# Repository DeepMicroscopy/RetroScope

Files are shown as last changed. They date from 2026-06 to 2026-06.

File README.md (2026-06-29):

<picture>
  <source media="(prefers-color-scheme: dark)" srcset="retroscope/qml/icons/app_logo_dark.png">
  <source media="(prefers-color-scheme: light)" srcset="retroscope/qml/icons/app_logo_light.png">
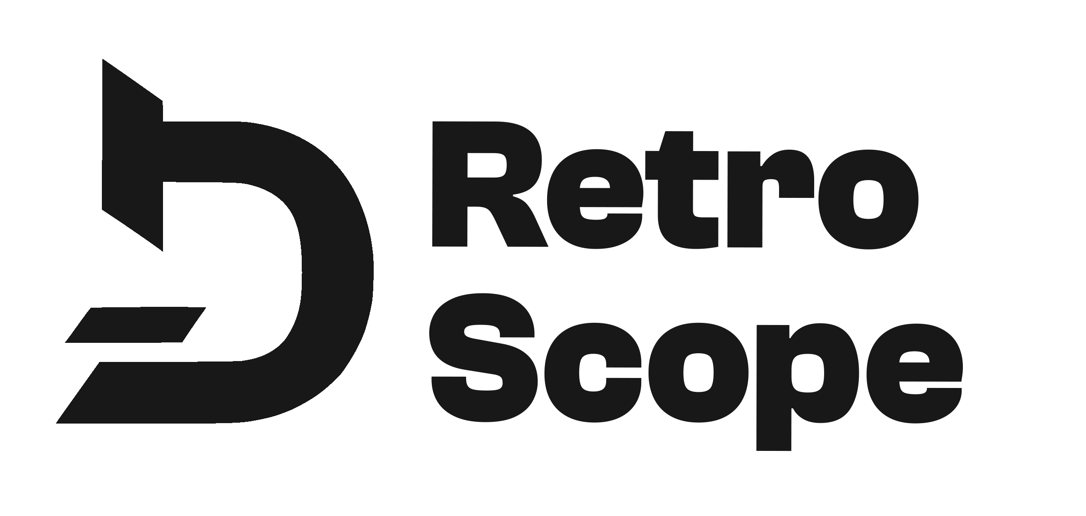
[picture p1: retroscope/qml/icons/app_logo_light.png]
RetroScope
  
</picture>

---

**An Open Framework for Motorizing and Digitizing Vintage Microscopes**

RetroScope is an open-source framework for older analog microscopes. It combines software, digital imaging, motorized stage and focus control, calibration workflows, and adaptable mechanical parts so that existing microscopes can be upgraded instead of replaced.

<p align="center">
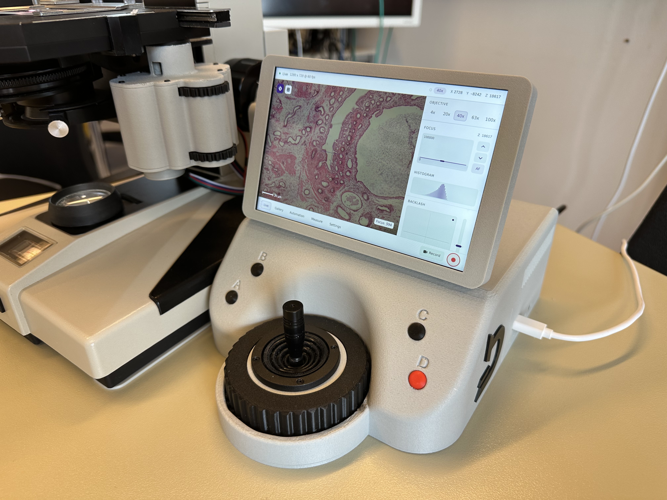
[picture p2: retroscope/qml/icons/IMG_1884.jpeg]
RetroScope
  
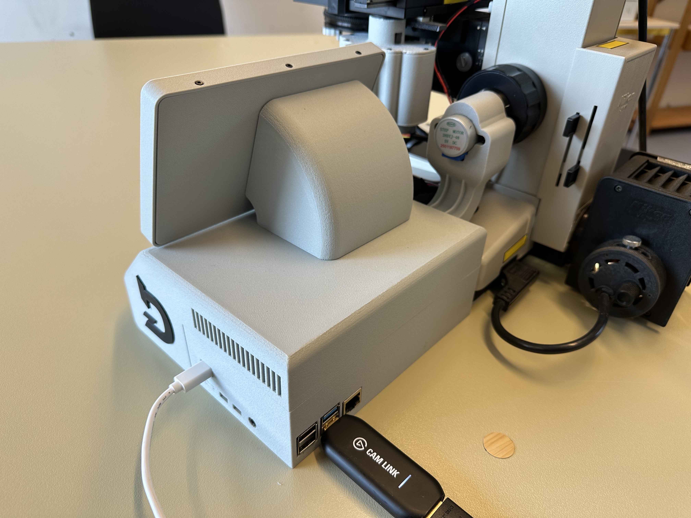
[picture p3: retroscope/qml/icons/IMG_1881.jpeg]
RetroScope
  
</p>

The project was developed as part of the master's thesis **"Retrofitting a Vintage Microscope: Development of an Embedded System for Motorized Control and Digital Imaging"** in Applied Computer Science at Flensburg University of Applied Sciences.

## Overview

RetroScope is not just a single application. It is intended as a complete retrofit framework:

- **Control software**: Python/PySide6 backend with a QML touchscreen interface.
- **Embedded system**: Raspberry Pi-based embedded system with mock/development support for desktop.
- **Motor control**: XY stage and Z focus movement through a motor controller ([Sangaboard](https://build.openflexure.org/openflexure-microscope/v7.0.0-beta5/parts/electronics/sangaboard.html)).
- **Digital imaging**: Live camera preview, snapshots, video recording, OME-TIFF support and gallery management.
- **Automation**: Autofocus, focus stacking and tile scanning with stitching support.
- **REST API**: FastAPI with Swagger/OpenAPI documentation for e.g. external tools.
- **Calibration**: Calibration wizards with objective profiles, pixel scale, stage scale, backlash compensation, etc.
- **Electronics**: PCB schematics and Gerber files for manufacturing. Optional, just used to reduce the amount of cabling.
- **Mechanical design**: Parametric Fusion/CAD files and 3D-printable parts for adapting the retrofit to different microscopes.

## Features

- Low-latency live microscope view with overlays such as crosshair, scale bar and grid.
- Objective profile system for different magnifications and numerical apertures.
- Camera-assisted calibration for image scale, stage scale, and backlash compensation
- Manual stage and focus control through touchscreen, joystick, and configurable buttons.
- Contract-based autofocus.
- Automated focus stacks and tile scans.
- Measurement tools for distances, rectangles and angles.
- Gallery for snapshots, videos, focus stacks, scans, and tagging.
- REST API to access captures and trigger actions like autofocus.
- Configurable dark/light UI
- Mock mode for development without microscope hardware.

## Screenshots

<p align="center">
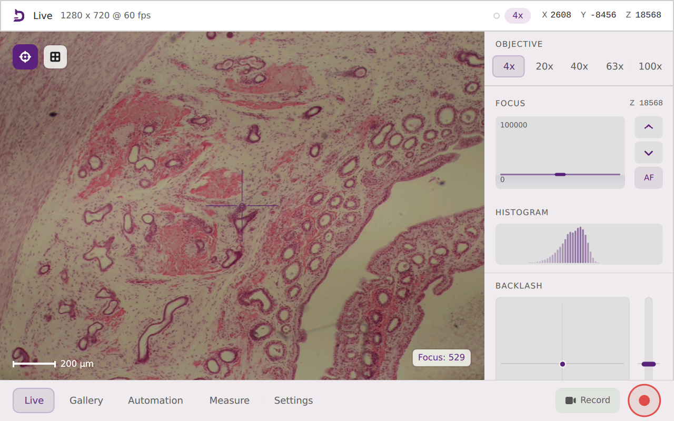
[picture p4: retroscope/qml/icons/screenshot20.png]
RetroScope
  
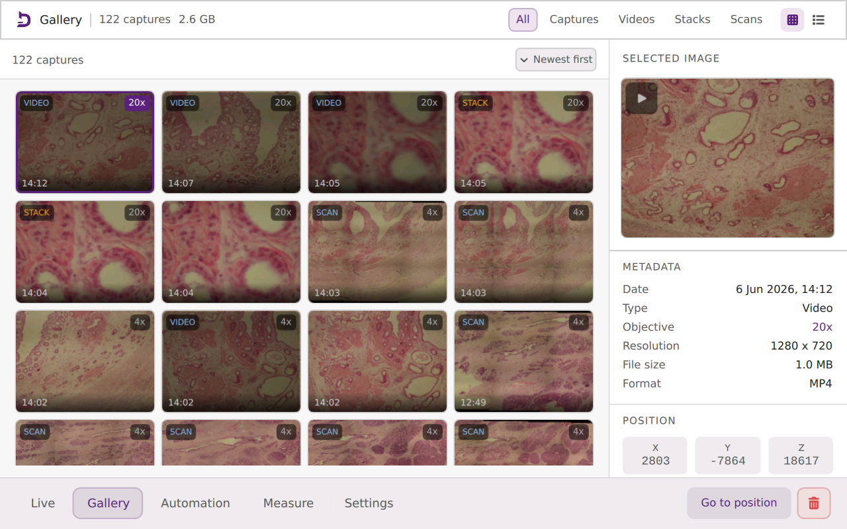
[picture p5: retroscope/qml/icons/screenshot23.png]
RetroScope
  
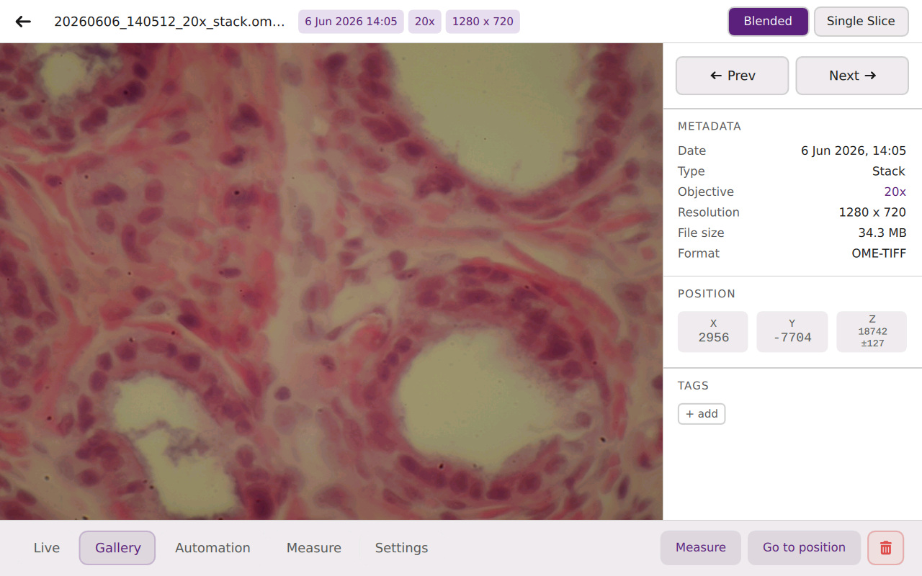
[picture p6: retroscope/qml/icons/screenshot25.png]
RetroScope
  
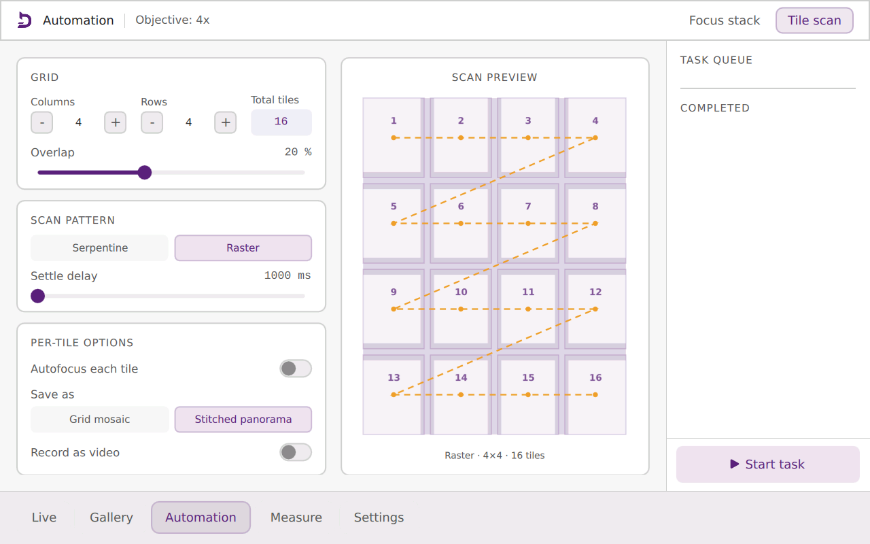
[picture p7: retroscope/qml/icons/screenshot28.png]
RetroScope
  
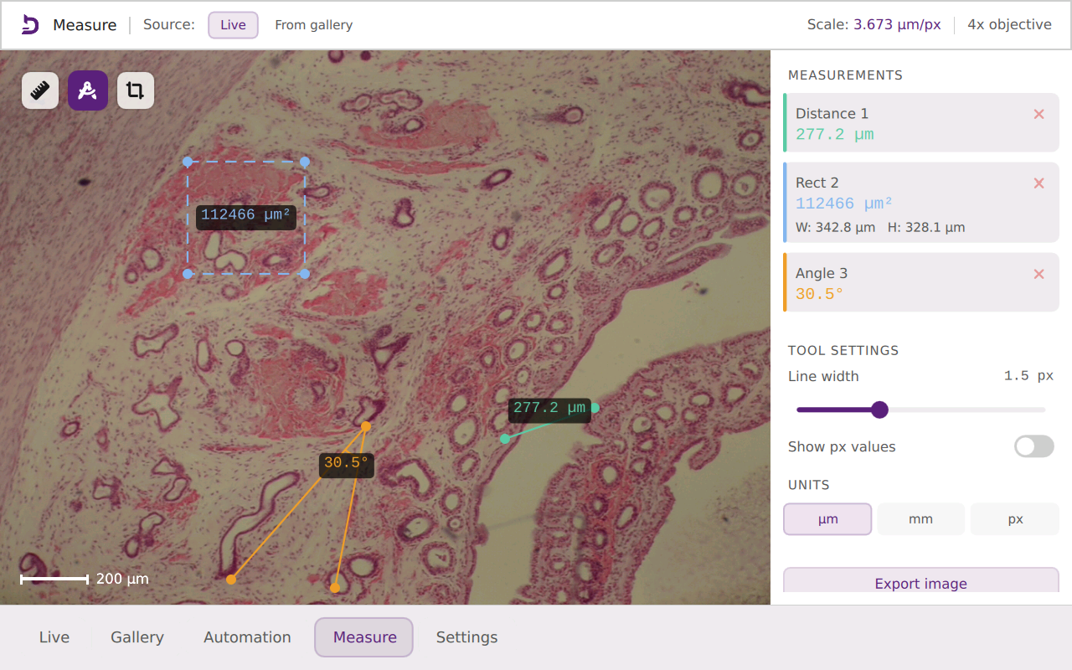
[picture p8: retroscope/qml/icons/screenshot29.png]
RetroScope
  
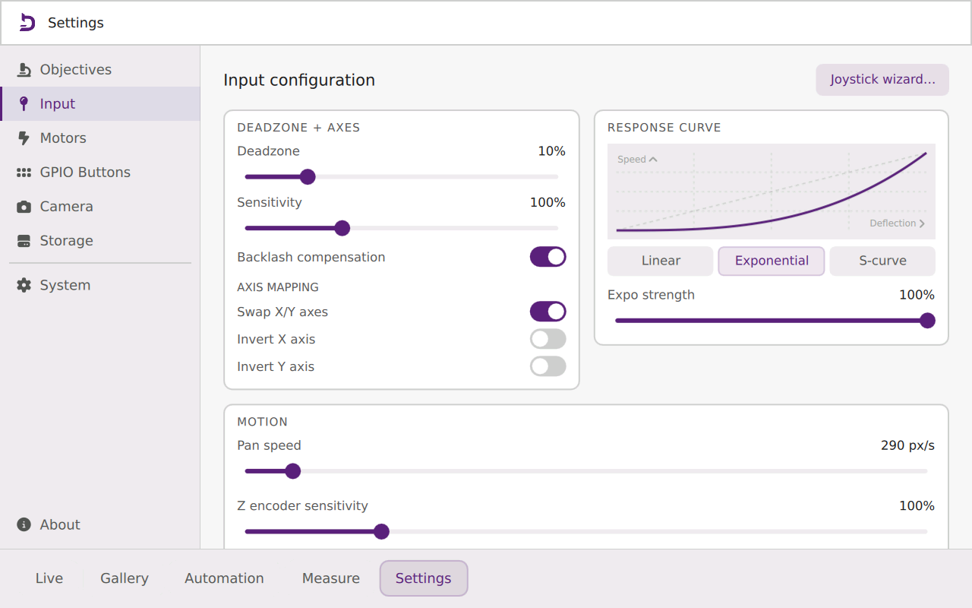
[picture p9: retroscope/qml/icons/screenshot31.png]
RetroScope
  
</p>

## Software Architecture

The software is organized into modular layers:

- `retroscope/drivers`: Low-level hardware drivers for camera input, Sangaboard motor control, joystick ADC, buttons, and endstop.
- `retroscope/services`: Application logic for motion, autofocus, calibration, camera processing, tile scanning, focus stacking, updates, ...
- `retroscope/api`: FastAPI REST interface and OpenAPI/Swagger documentation.
- `retroscope/domain`: Pure domain modules (+ calculations) for scan planning, focus metrics, objective calibration, measurement, ...
- `retroscope/bridge`: Qt/PySide bridge objects that expose APIs to QML.
- `retroscope/qml`: Touchscreen user interface components and views.
- `tests`: Unit tests for calibration, autofocus, motion, scanning, settings, ...

This separation enables the expansion of individual subsystems without rewriting the entire platform.

## Hardware Recommendations

The following parts were used for the prototype:

- Raspberry Pi 4 Model B, 4 GB RAM
- [Sangaboard](https://build.openflexure.org/openflexure-microscope/v7.0.0-beta5/parts/electronics/sangaboard.html)
- 3x 28BYJ-48 Stepper Motors
- DSI Capacitive Touch Display
- Analog Joystick with 10k Potentiometers
- ADS1115 ADC Modul
- Incremental Rotary Encoder
- Bearing (60mm * 78mm * 10mm)
- Endstop
- 4x Buttons
- Various cables
- ABS (& PETG) filament/s for 3D printed parts
- Optional Custom PCB

## Installation

Clone the repository and create a virtual environment:

```bash
git clone https://github.com/marvincarstensen/RetroScope.git
cd retroscope
python[3] -m venv .venv
source .venv/bin/activate
pip install -r requirements.txt
```

For Raspberry Pi deployment, an additional setup script, to e.g. setup the service, has to be run with sudo:
```bash
sudo bash deploy/setup.sh
```

## Running

Start the application:

```bash
python app.py
```
> [!NOTE]
> First launch may take a little longer while Python builds its caches.

Run in mock mode for desktop env:

```bash
python app.py --mock
```

Enable development mode with QML hot reloading:

```bash
python app.py --mock --dev
```

Apply a UI scale factor:

```bash
python app.py --scale 1.5
```

On the Raspberry Pi with Wayland:

```bash
WAYLAND_DISPLAY=wayland-0 XDG_RUNTIME_DIR=/run/user/1000 python app.py --scale=1.5
```

## Testing

Run the test suite:

```bash
.venv/bin/python -m pytest -q
```

Compile-check on the package:

```bash
.venv/bin/python -m compileall -q retroscope
```

Run QML lint checks:

```bash
.venv/bin/pyside6-qmllint -I retroscope/qml $(find retroscope/qml -name '*.qml')
```

## Evaluation

The evaluations run inside the main application so they use the real camera pipeline, motion
services, calibration state, and workflow services. Results are written as CSV files to
`evaluation_output/`, with per-trial rows followed by summary rows. Needs a textured specimen and a safe stage position to run properly. The active objective needs to be selected and calibrated before running measurements.

Available evaluation types:

- `motion_accuracy`: compares commanded X/Y movement with measured image displacement and backlash residuals.
- `stage_scale`: measures repeated stage-scale estimates in micrometres per motor step.
- `calibration_repeat`: repeats stage-scale and backlash checks for the active objective.
- `workflow_reliability`: runs autofocus, focus stacking, and tile scanning through the app services.

Example runs:

```bash
python app.py --eval motion_accuracy --eval-arg axes=xy --eval-arg steps=100,200 --eval-arg reps=10
python app.py --eval stage_scale --eval-arg steps=100 --eval-arg reps=10
python app.py --eval calibration_repeat --eval-arg stage_steps=200 --eval-arg reps=10
python app.py --eval workflow_reliability --eval-arg reps=10 --eval-arg workflows=autofocus,focus_stacking,tile_scanning
```

## REST API

By default, the API is enabled and listens on port `8765`:

- `http://127.0.0.1:8765` / `http://<device-ip>:8765`
- Swagger UI: `http://<device-ip>:8765/docs`
- OpenAPI JSON: `http://<device-ip>:8765/openapi.json`

The current API is intentionally small and intended as an extension point for scripts, notebooks, and external tools.

Endpoint                                  | Description
------------------------------------------|-------------------------------
`GET /api/v1/health`                      | API health check.
`GET /api/v1/captures`                    | List gallery captures.
`GET /api/v1/captures/{id}/download`      | Download the original capture file.
`POST /api/v1/actions/autofocus`          | Start autofocus.
`POST /api/v1/actions/capture`            | Start capture.

## Demo Notebook

The repository contains a basic Jupyter notebook, `retroscope_api_demo.ipynb`, that demonstrates how to use the REST API.

## Shortcuts (Mock only)

The following keyboard shortcuts can be used in mock simulation:

Key       | Function           
----------|-------------------
WASD      | Joystick axes        
Space     | Joystick center (release)         
+/-       | Encoder step +-1       
1/2/3/4   | Button press 0–3      
E         | Simulate endstop triggered/released toggle

## Dependencies

The following plugins, libraries and frameworks are used:

Name                    | Version           
------------------------|-------------------
PySide6                 | 6.11.1
fastapi                 | 0.136.3
httpx2                  | 2.3.0
uvicorn                 | 0.49.0
numpy                   | 2.4.6
pytest                  | 9.0.3
opencv-python-headless  | 4.13.0.92
Pillow                  | 12.2.0
tifffile                | 2026.5.15
sangaboard              | 0.3.3
smbus2 (only on Pi)     | 0.6.1           
gpiod (only on Pi)      | 2.4.2   

## Additional Sources

- Font Awesome by Dave Gandy (https://fontawesome.com/)
- LateX Template, Logo & CI (DeepMicroscopy) by Nils Porsche

## Declaration: Use of Generative AI

The following generative AI tools were used in this thesis: 

- GitHub Copilot in VS Code was used for inline code-completion suggestions during implementation and writing.
- ChatGPT (OpenAI) & Claude (Anthropic) used to support brainstorming, quick research, and the generation of selected parts of the code (e.g. unit tests). AI-assisted scripts and functions are marked in the source code via comments.
- DeepL write (DeepL SE) were used in language editing and grammatical proof-reading.

All AI-generated material was critically reviewed, edited, and verified by the author. No generative AI system was used to produce original scientific results, experimental data, proofs, or final implementations of algorithms. The author assumes full responsibility for the content, correctness, and originality of this thesis.

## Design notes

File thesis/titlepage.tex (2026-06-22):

\begin{tikzpicture}[remember picture,overlay]
  \node[
    anchor=north east,
    xshift=-1cm,
    yshift=-1cm,
    inner sep=0pt   % additional spacing
  ] at (current page.north east) {%
    %
  };
\end{tikzpicture}

\vspace*{-2cm}

\begin{center}
    \textbf{Hochschule Flensburg}\\
    Flensburg University of Applied Sciences\\
    \vspace{2cm}
    \textbf{\LARGE M A S T E R \ \ T H E S I S}
\end{center}

\vspace{2cm}

\begin{tabbing}
    Topic: \hspace{3cm} \= \textbf{Retrofitting a Vintage Microscope:}\\[0.1cm]
    \> Development of an Embedded System for \\[0.1cm]
    \> Motorized Control and Digital Imaging \\[0.5cm]
    by: \> \textbf{Marvin Carstensen}\\[2cm]
    Student ID number: \>\textbf{780241} \\[0.5cm]
    Degree course: \> \textbf{Applied Computer Science (M.Sc.)} \\[0.5cm]
    Supervisor and \\
    primary evaluator: \>\textbf{Prof. Dr.-Ing. Marc Aubreville} \\[0.5cm]
    Secondary evaluator: \> \textbf{Prof. Dr. Simon Olberding} \\[0.5cm]
    Date of issue: \> \textbf{24.03.2026} \\[0.5cm]
    Date of submission: \> \textbf{22.06.2026}
\end{tabbing}

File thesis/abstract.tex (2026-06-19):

Many optical microscopes remain mechanically and optically useful for decades, even when they no longer match the digital and automated workflows expected in modern laboratories or teaching environments. Replacing such instruments can be expensive and wasteful. This thesis investigates whether a vintage microscope can instead be extended with motorized movement, digital imaging, calibration, and automated capturing while preserving the existing microscope body.

The result is RetroScope, an open retrofit platform for motorizing and digitizing vintage microscopes. The prototype attaches motors to the microscope's existing focus and XY-stage controls instead of replacing the whole microscope. A parametric 3D-printable adapter model is used so that important dimensions, such as knob positions and mounting geometry, can be adjusted for various microscope bodies. The system combines low-cost embedded hardware, a custom printed circuit board, a Raspberry Pi, a camera input, and a touchscreen user interface.

The software is designed as a modular application that connects hardware control, live video, calibration, image storage, and automated workflows. Image-based calibration links camera pixels, motor steps, objective profiles, scale information, focus settings, and backlash compensation. This allows the system to support practical workflows such as autofocus, focus stacking, tile scanning, calibrated measurement, and remote access via REST API.

The evaluation shows that the prototype can support these workflows under controlled conditions and that calibration and compensation are essential for making low-cost open-loop mechanics usable. At the same time, the results show clear limitations: the system estimates position from motor commands rather than measuring it directly, and mechanical flex, and backlash still bound the achievable accuracy. RetroScope therefore does not replace a precision research microscope. Instead, it demonstrates a resource-conscious way to give vintage microscopes programmable motion, workflows, and digital capture without discarding the original instrument.

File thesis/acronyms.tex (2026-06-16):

\begin{acronym}[OME-TIFF]
    \acro{ABS}[ABS]{Acrylonitrile butadiene styrene, a printable thermoplastic used for stronger prototype parts.}
    \acro{ABSGF}[ABS-GF]{Glass-fiber-reinforced acrylonitrile butadiene styrene, used for stiffer printed parts.}
    \acro{ADC}[ADC]{Analog-to-digital converter, used to convert analog joystick voltages into digital values.}
    \acro{AF}[AF]{Autofocus.}
    \acro{AI}[AI]{Artificial intelligence.}
    \acro{API}[API]{Application programming interface, a software interface exposed for other programs.}
    \acro{BCM}[BCM]{Broadcom GPIO numbering scheme used by the Raspberry Pi.}
    \acro{BSS138}[BSS138]{A MOSFET commonly used in small logic-level shifter modules.}
    \acro{CAD}[CAD]{Computer-aided design.}
    \acro{CPU}[CPU]{Central processing unit.}
    \acro{CSV}[CSV]{Comma-separated values, a plain-text table format used for evaluation results.}
    \acro{DoF}[DoF]{Depth of field.}
    \acro{DSI}[DSI]{Display Serial Interface, used by the Raspberry Pi touchscreen.}
    \acro{FIFO}[FIFO]{First in, first out, a queue behavior used in serial communication buffers.}
    \acro{GB}[GB]{Gigabyte.}
    \acro{GND}[GND]{Ground reference in the electronics wiring.}
    \acro{GPIO}[GPIO]{General-purpose input/output pins on the Raspberry Pi.}
    \acro{I2C}[I\textsuperscript{2}C]{Inter-Integrated Circuit, a serial bus used by the ADC, current sensors, and touchscreen controller.}
    \acro{JSON}[JSON]{JavaScript Object Notation, a structured text format used for configuration and API data.}
    \acro{JST}[JST]{A family of small electrical connector types used in wiring harnesses.}
    \acro{NA}[NA]{Numerical aperture of a microscope objective.}
    \acro{OME}[OME]{Open Microscopy Environment.}
    \acro{OMETIFF}[OME-TIFF]{Open Microscopy Environment TIFF, a microscopy image format with structured metadata.}
    \acro{OMEXML}[OME-XML]{Open Microscopy Environment XML metadata embedded in or associated with microscopy image files.}
    \acro{OpenCV}[OpenCV]{Open Source Computer Vision Library.}
    \acro{PCB}[PCB]{Printed circuit board.}
    \acro{PETG}[PETG]{Polyethylene terephthalate glycol, a 3D-printing filament material.}
    \acro{PNG}[PNG]{Portable Network Graphics image format.}
    \acro{QML}[QML]{Qt Modeling Language, the declarative language used for the touchscreen user interface.}
    \acro{REST}[REST]{Representational State Transfer, an architectural style used for the HTTP API.}
    \acro{RQ}[RQ]{Research question.}
    \acro{SCL}[SCL]{Serial clock line of an I\textsuperscript{2}C bus.}
    \acro{SDA}[SDA]{Serial data line of an I\textsuperscript{2}C bus.}
    \acro{STEP}[STEP]{Standard for the Exchange of Product Data, a CAD exchange file format.}
    \acro{TIFF}[TIFF]{Tagged Image File Format.}
    \acro{UART}[UART]{Universal asynchronous receiver-transmitter, a serial communication interface.}
    \acro{UI}[UI]{User interface.}
    \acro{USB}[USB]{Universal Serial Bus.}
    \acro{UVC}[UVC]{USB Video Class, a standard for USB camera and capture devices.}
    \acro{V4L2}[V4L2]{Video4Linux2, the Linux video capture interface.}
\end{acronym}

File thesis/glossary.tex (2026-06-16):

\makeglossaries

\newglossaryentry{retrofitting}
{
    name={retrofitting},
    description={the modification of an existing instrument, system or machine so that it gains functionality that was not part of the original design}
}

\newglossaryentry{backlash}
{
    name={backlash},
    description={lost motion that occurs when a drive mechanism changes direction before mechanical contact is re-established}
}

\newglossaryentry{frameanalysis}
{
    name={frame analysis},
    description={the reduced-rate image-processing path used for histogram computation, focus scoring, calibration support, and related live metrics}
}

\newglossaryentry{ometiff}
{
    name={OME-TIFF},
    description={an image format that stores microscopy image planes in TIFF files and encodes microscopy metadata using the OME data model}
}

\newglossaryentry{openloop}
{
    name={open-loop control},
    description={motion control in which motor commands are issued without continuous measurement of the resulting physical position}
}

\newglossaryentry{sangaboard}
{
    name={Sangaboard},
    description={an open-source motor-controller board that drives stepper motors and reports motor step counts to a host over a serial (UART) link}
}

\newglossaryentry{hysteresisband}
{
    name={hysteresis-band model},
    description={a backlash-compensation model that tracks a per-axis slack estimate within a band whose width equals the measured backlash, adding the slack take-up to a move only when the direction reverses}
}

\newglossaryentry{pixelscale}
{
    name={pixel scale},
    description={the physical distance in the specimen plane that corresponds to image pixels for a given objective and camera configuration, expressed in micrometers per pixel}
}

\newglossaryentry{stagescale}
{
    name={stage scale},
    description={the physical stage movement produced by one motor step, calibrated separately for the X and Y axes and expressed in micrometers per step}
}

\newglossaryentry{objectiveprofile}
{
    name={objective profile},
    description={the stored set of per-objective calibration values, including magnification, numerical aperture, pixel scale, backlash, depth-of-field steps, focus-stack step, and autofocus range}
}

\newglossaryentry{depthoffield}
{
    name={depth of field},
    description={the range of object distances along the optical axis that appears acceptably sharp at a given objective, used to choose focus-stack spacing and autofocus range}
}

\newglossaryentry{focusstacking}
{
    name={focus stacking},
    description={the capturing of several images at different focus positions and their combination into a single image with greater apparent depth of field}
}

\newglossaryentry{tilescanning}
{
    name={tile scanning},
    description={the capturing of a grid of overlapping fields of view that are combined into a larger image, either as a stitched panorama or as a deterministic grid mosaic}
}

\newglossaryentry{phasecorrelation}
{
    name={phase correlation},
    description={a frequency-domain image-registration method used to estimate the sub-pixel translational shift between overlapping tiles during stitching}
}

\newglossaryentry{deadzone}
{
    name={dead zone},
    description={a region of small joystick deflection around the center that is mapped to zero motion to prevent drift from noise or imperfect centering}
}

\newglossaryentry{mockmode}
{
    name={mock mode},
    description={a desktop development mode in which hardware-dependent drivers are replaced by stand-ins so that the application can run without the physical microscope}
}

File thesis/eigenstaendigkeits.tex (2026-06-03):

I hereby declare that I have written this thesis independently and without outside help, that I have used no sources or aids other than those indicated, that I have marked all passages taken from other works either verbatim or in substance, including generated texts, and that this thesis has not been submitted in the same or a similar form in any other examination. I consent to the thesis being checked by plagiarism-detection software.\\*

\vspace{25mm}
\begin{tabular}{@{}p{4cm}p{2cm}p{4cm}@{}}
\hrulefill && \hrulefill\\
Place, Date && Signature\\
\end{tabular}

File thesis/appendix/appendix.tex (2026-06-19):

\subsection{Bill of Materials and Cost Breakdown}\label{app:bom}

Table~\ref{tab:components} lists the components and their role. The priced breakdown below records the component cost of the built prototype, prices vary by supplier and date. Not included are tools and equipment (3D printer, soldering station, etc.), microscope and camera.

\begin{table}[H]
    \centering
    \caption[Priced bill of materials]{Priced bill of materials.}
    \label{tab:bom-priced}
    \begin{tabular}{@{}L{5.8cm} c c c@{}}
        \toprule
        \textbf{Item} & \textbf{Qty} & \textbf{Unit price} & \textbf{Supplier} \\
        \midrule
        Raspberry Pi 4 Model B (4\,GB) & 1 & 105,90 \euro & Amazon \\
        7inch DSI Capacitive Touch Display & 1 & 76,99 \euro & Amazon \\
        Elgato Cam Link 4K & 1 & 99,99 \euro & Amazon \\
        Sangaboard v5 & 1 & 32,44 \euro & TauLab LTD \\
        28BYJ-48 motor & 3 & 2,79 \euro & Amazon \\
        Joystick with 10k potentiometers & 1 & 26,68 \euro & Amazon \\
        ADS1115 & 1 & 4,33 \euro & Amazon \\
        Incremental Rotary Encoder & 1 & 15,98 \euro & Amazon \\
        INA219 & 2 & 2,989 \euro & Amazon \\
        Ball bearing & 1 & 9,29 \euro & Amazon \\
        End stop & 1 & 0,649 \euro & Amazon \\
        Logic Level Converter (BSS138) & 1 & 0,749 \euro & Amazon \\
        Custom PCB (manufacturing) & 1 & 3,83 \euro & JLCPCB \\
        Filament (PETG) & 1 & 2,30 \euro \hspace{0.01cm} (Spool: 11,50 \euro) & Bambu Store \\
        Filament (ABS-GF) & 1 & 15,99 \euro \hspace{0.01cm} (Spool: 31,99 \euro) & Bambu Store \\
        Wires, Buttons, Connectors, etc. & 1 & \(\approx\) 10 \euro & (Diverse) \\
        \midrule
        \textbf{Total system cost} & & \(\approx\) 419,47 \euro & \\
        \bottomrule
    \end{tabular}
\end{table}

\subsection{Custom PCB Schematic and Gerber Reference}\label{app:pcb}

The KiCad project is contained in the repository under \texttt{cad/pcb/}. The relevant files are the schematic (\texttt{Retroscope.kicad\_sch}), the board layout (\texttt{Retroscope.kicad\_pcb}), the project and symbol files (\texttt{Retroscope.kicad\_pro}, \texttt{Retroscope.kicad\_sym}), the 3D model export (\texttt{Retroscope.step}), the manufacturing Gerbers, and the drill files. The board carries the joystick/ADS1115 path, two INA219 current-sense modules, the BSS138 logic-level shifter, endstop/button connectors, and 5\,V/3.3\,V power rails with a common ground. The board was manufactured through JLCPCB.

\begin{figure}[H]
    \centering
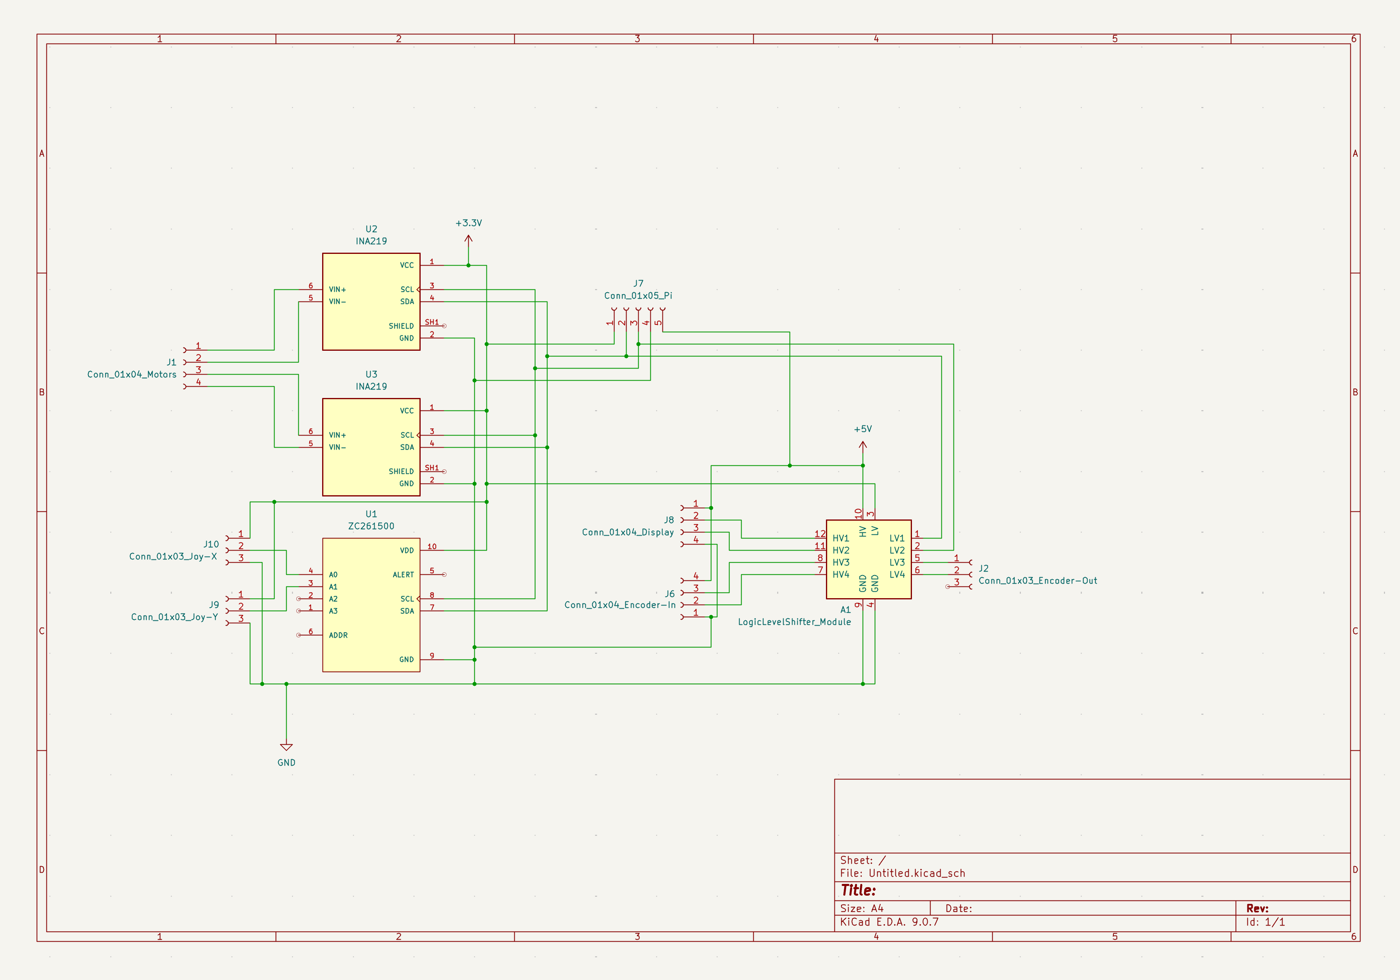
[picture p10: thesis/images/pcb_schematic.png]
    
    \caption[Custom PCB schematic]{Custom PCB schematic exported from KiCad.}
    \label{fig:pcb-schematic}
\end{figure}

\subsection{GPIO, I\textsuperscript{2}C, UART, and Power Wiring}\label{app:wiring}

The pin and address assignments are summarised in Table~\ref{tab:wiring}. The Sangaboard uses the Raspberry Pi UART on GPIO~14/15, which requires Bluetooth to be disabled so that the full UART is available. Additional Sangaboard control and step-signalling lines use GPIO~4, 8, 11, 23, 24, and 25. The rotary encoder is connected through GPIO~17 and 27 and passes through a 5\,V\ to 3.3\,V logic-level shifter to protect the Raspberry Pi inputs. The Z endstop uses GPIO~16, and the four user buttons use GPIO~6, 13, 19, and 26.

The I\textsuperscript{2}C bus on GPIO~2/3 is shared by the ADS1115 joystick ADC at address 0x48, two INA219 current-sense modules at 0x40 and 0x41, and the touchscreen controller/backlight at 0x38 and 0x45. All modules share common 5\,V, 3.3\,V, and ground rails. Figure~\ref{fig:fritzing} shows the corresponding Fritzing breadboard wiring overview. It includes the complete prototype wiring context, including the Raspberry Pi, motor controller, input devices, sensors, and power rails, rather than only the connectors on the custom PCB.

\begin{figure}[H]
    \centering
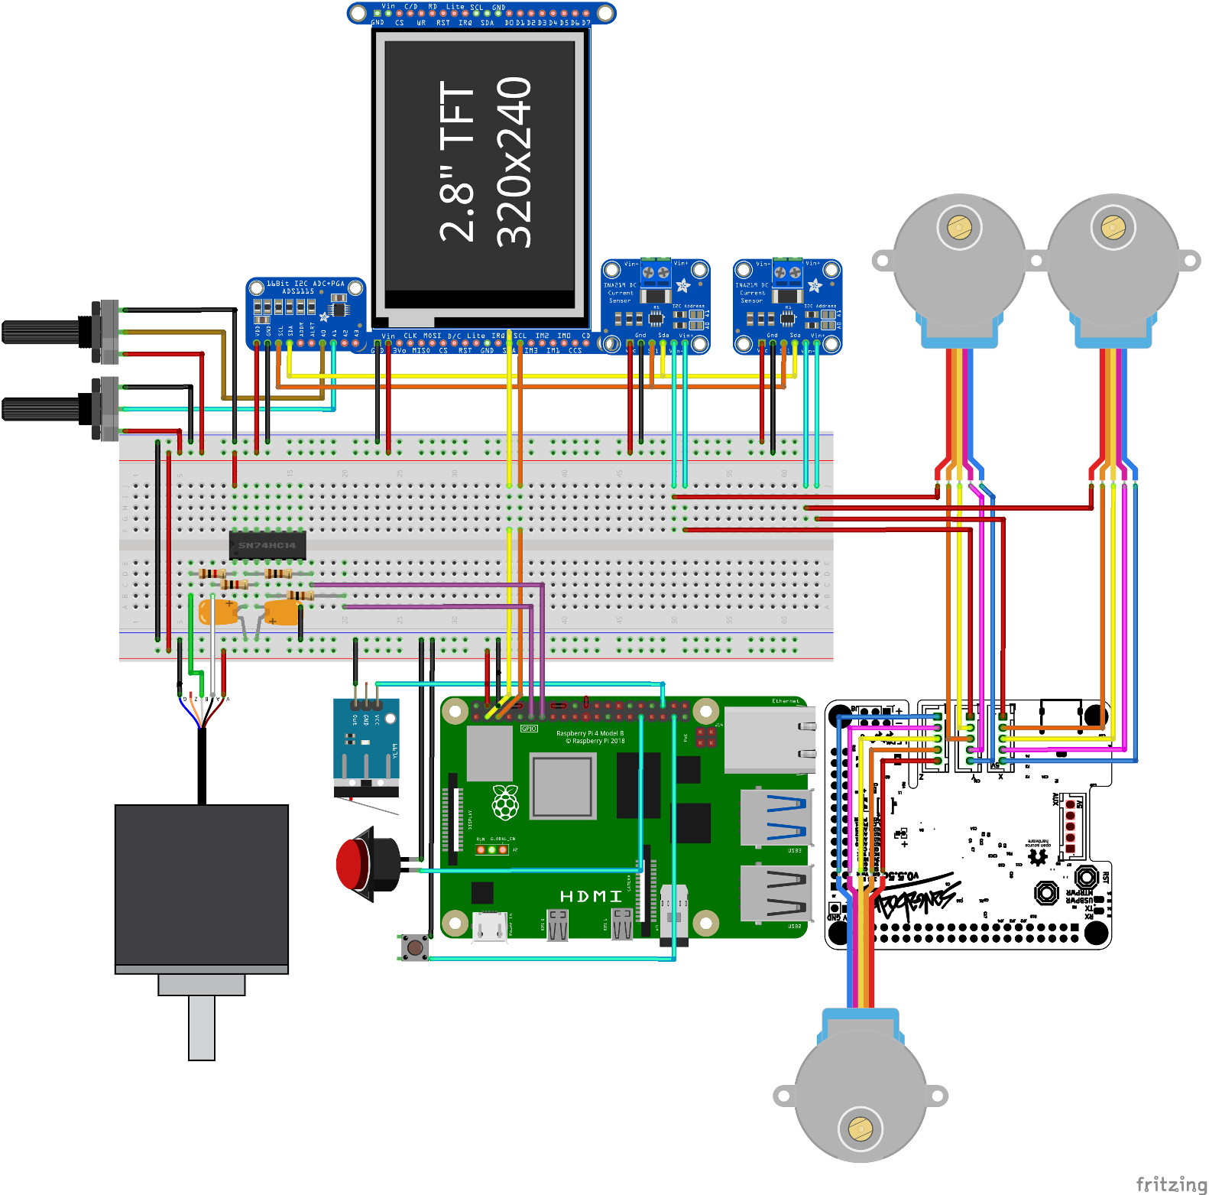
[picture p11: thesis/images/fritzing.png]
    
    \caption[Fritzing wiring overview]{Fritzing breadboard wiring overview of the full RetroScope prototype, including the Raspberry Pi, Sangaboard, input devices, sensors, and shared power rails.}
    \label{fig:fritzing}
\end{figure}

\subsection{Parametric Fusion Model Parameters}\label{app:fusion}

The parametric model is exported as \texttt{cad/ParametricModel.f3z}. The parameters in Table~\ref{tab:fusion} control the microscope-specific geometry: \texttt{connection\_hole} parameters set feet positions and radii, the \texttt{z\_assembly} parameters set the focus sub-assembly height and offsets, and the \texttt{xy\_assembly} offsets shift the XY sub-assembly. Adapting the platform to another microscope is intended to proceed by changing these parameters rather than rebuilding the assembly.

\subsection{3D-Printing and Assembly Notes}

Prototype parts were printed in PETG for rapid iteration and ABS-GF for stiffer, load-heavy parts. Heat-set threaded inserts were used where repeated assembly or stronger threads were required. Exact slicing settings (nozzle, layer height, infill, perimeters) are recorded in Table~\ref{tab:print}.

\subsection{Backlash and Stage-Scale Measurement Data}\label{app:measure}

The measurement protocols and result tables are defined in Section~\ref{sec:calibration} (Table~\ref{tab:stagescale}) and Section~\ref{sec:evaluation} (Table~\ref{tab:motion}). The raw repeated-measurement data was recorded to the \texttt{thesis/evaluation\_output} directory in the repository.

\subsection{REST API Endpoint Reference}\label{app:api}

The API is served by FastAPI/Uvicorn on port~8765 by default, with Swagger UI at \texttt{/docs} and the OpenAPI document at \texttt{/openapi.json}. Table~\ref{tab:api} lists the endpoints.

\subsection{Configuration Examples}\label{app:config}

The default configuration is stored as JSON in the repository \texttt{retroscope/config/default\_config.json}. Listing~\ref{lst:config} shows a representative snippet of
an objective profile and the motor and autofocus groups.

\begin{lstlisting}[basicstyle=\ttfamily\footnotesize, frame=single, caption={Snippet of the default configuration.}, label={lst:config}]
"objectives": {
    "4x":  { 
        "numerical_aperture": 0.1, 
        "um_per_pixel": 3.6727,
        "backlash_x": 100, 
        "backlash_y": 200,
        "backlash_z": 20,
        "dof_steps": 803, 
        "focus_stack_step": 402,
        "autofocus_range_steps": 8030 
    }
},
"motor": {
    "stage_um_per_step_x": 2.2648,
    "stage_um_per_step_y": 3.2720,
    "sangaboard_step_time_us": 1000,
    "sangaboard_ramp_time_us": 25000
},
"autofocus": {
    "settle_ms": 150,
    "move_start_ms": 400,
    "coarse_positions": 11,
    "fine_positions": 13,
    "min_confidence": 70.0
}
\end{lstlisting}

\subsection{User Interface Screenshots}\label{app:ui}

\begin{figure}[H]
    \centering
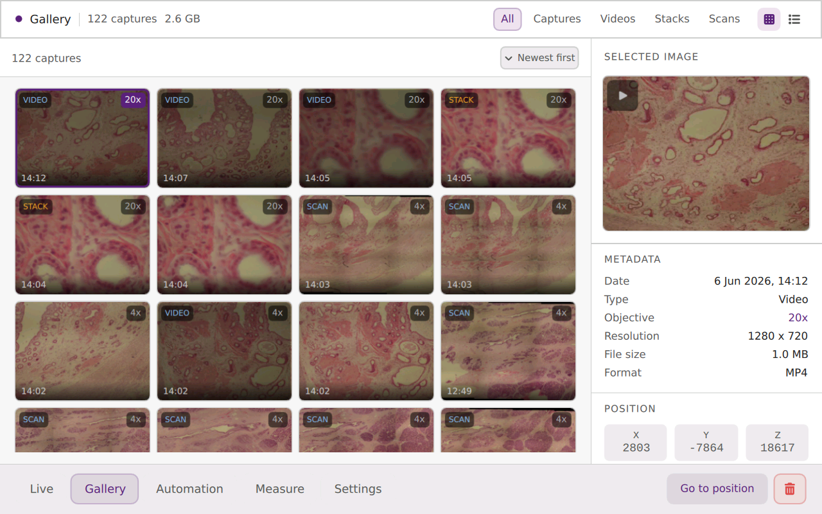
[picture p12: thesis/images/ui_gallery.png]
    
    \caption[Gallery view]{Gallery view with capture grid view.}
    \label{fig:ui-gallery}
\end{figure}

\begin{figure}[H]
    \centering
    
    \caption[Tile-scan workflow view]{Tile-scan workflow view with scan pattern preview.}
    \label{fig:ui-calibration}
\end{figure}

\subsection{Installation and Deployment Guide}\label{app:deploy}

The application is a Python/PySide6 project. A typical installation starts by cloning the repository, creating a virtual environment, and installing the Python requirements. On a desktop system the application can be started in mock mode with \texttt{python app.py --mock}. This allows UI, gallery, calibration, and workflow development without the physical microscope. The first launch may take a
little longer because Python creates its bytecode caches.

For Raspberry Pi deployment, the hardware interfaces must be prepared before the application is used: I\textsuperscript{2}C must be enabled for the ADS1115, INA219 modules, and touchscreen controller, and the full PL011 UART must be available for Sangaboard communication. In the prototype this means disabling Bluetooth so that GPIO~14/15 can be used as the stable UART interface. The physical wiring is described in Table~\ref{tab:wiring} and Figure~\ref{fig:fritzing}.

After the Python environment and hardware configuration are in place, the Raspberry Pi setup script is run once with sudo privileges using \texttt{sudo bash deploy/setup.sh}. The script links the repository into the expected application path if necessary, installs and enables the \texttt{retroscope.service} systemd service, adds the shutdown permission used by the UI, and applies the custom boot splash configuration. A reboot is required after this setup.

The service starts \texttt{deploy/start.sh \--\--scale 1.5}. This launcher activates an available virtual environment, uses a lock file to avoid multiple application instances, and restarts the application only when the application exits with the dedicated restart code. When running on the Raspberry Pi desktop without the service, the application can also be started manually under Wayland with the appropriate \texttt{WAYLAND\_DISPLAY} and \texttt{XDG\_RUNTIME\_DIR} environment variables. The running application provides the touchscreen UI locally and the REST API on port~8765 for remote capture access and selected actions.

\subsection{List of Released Open-Source Artifacts}\label{app:artifacts}

The released project artifacts are available in the public GitHub repository \url{https://github.com/DeepMicroscopy/RetroScope}. The repository contains the Python/PySide6/QML application, default configuration, deployment scripts, REST API implementation, demonstration Jupyter notebook, KiCad PCB project, the parametric Fusion model export (\texttt{ParametricModel.f3z}), and project documentation.

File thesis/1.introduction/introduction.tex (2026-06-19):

\subsection{Motivation}

Optical microscopes are durable scientific instruments. Their mechanical frames, objective turrets, stages, and focusing mechanisms can remain usable for decades, while the surrounding laboratory work has changed considerably. Modern microscopy is increasingly shaped by digital image capture, automated workflows, and calibrated measurements. A working analog microscope can therefore still provide valuable optical performance while being separated from the software and automation practices that are common in current digital imaging.

Replacing such instruments with fully integrated motorized microscopes is often expensive and can be difficult to justify in teaching, small laboratories, and hobbyist contexts. A retrofit approach could offer a different path: Instead of discarding the existing optical instrument, the physical controls of the microscope could be motorized and digitized. This would be possible because many microscopes expose similar user-facing control interfaces, such as fine and coarse focus knobs and XY-stage knobs. These interfaces are intended for human operation, but they can also be used as attachment points for a motorized retrofit.

The central motivation of this thesis is to investigate whether a low-cost embedded system can turn a vintage microscope into a programmable digital imaging platform without replacing the microscope's internal mechanics. The work is not intended to compete with high-end commercial automation platforms in precision or completeness. Instead, it explores the space between purely manual microscopy and fully integrated commercial systems. Open-source scientific hardware has been proposed as a way to reduce the cost of research equipment and make instrumentation more reproducible \cite{pearce2012openhardware}. By preserving and extending existing microscopes, a retrofit approach can reduce waste while making digital microscopy more accessible.

\subsection{Problem Statement}

Retrofitting a microscope is a multidisciplinary problem. A useful platform must solve mechanical, electronic, software, and calibration challenges at the same time. Mechanically, a retrofit must connect motors to knobs that were designed for human hands, not for standardized actuators. The design must tolerate different microscope bodies and limited mounting space. Electronically, the platform must connect motors, user controls, sensors, display hardware, and camera input in a reproducible way. In software, the system must combine real-time manual control, camera preview, image processing, automation workflows, and a usable touchscreen interface.

The most difficult aspect is that low-cost retrofit hardware does not automatically provide reliable measurement. Inexpensive geared stepper can move the microscope stage and focus axis, but gear reduction, backlash, missed motion assumptions, and axis asymmetry causes the motor position differ from the optical position. A stage that moves by motor steps is therefore not yet a calibrated measurement device. The retrofit must estimate or calibrate the relationship between image pixels, physical distance, and motor steps, and it must compensate mechanical slack sufficiently for workflows such as focus stacking and tile scanning.

\clearpage

\subsection{Research Questions}

The work is guided by three research questions:

\begin{description}
    \item \textbf{RQ1: Parametric retrofit adaptability}\\
    Can a retrofit platform add motorized control and digital imaging to vintage microscopes while remaining adaptable to different mechanical designs through parametric modelling?
    \item \textbf{RQ2: Low-cost motion and positioning}\\
    Can a low-cost prototype provide sufficiently consistent motion, and positioning behavior for automated microscopy?
    \item \textbf{RQ3: Calibration-enabled workflows}\\
    To what extent can image-based calibration enable automated workflows such as autofocus, focus stacking, and tile scanning?
\end{description}

These questions frame "RetroScope" as an artifact-based contribution in Applied Computer Science. The thesis evaluates the design and behavior of a working prototype rather than proposing a new microscopy "standard".

\subsection{Contributions}

The thesis makes four main contributions:

First, it presents a parametric mechanical retrofit concept for coupling motors to existing microscope controls. The design uses 3D-printed adapters, motor mounts, gear elements, and brackets to drive the existing focus and XY-stage mechanisms instead of replacing them. The Fusion model is parameterized so that geometric dimensions such as knob locations, feet positions, and assembly offsets can be adapted to other microscope bodies.

Second, it presents a low-cost embedded hardware and software platform. The prototype combines a Raspberry Pi, touchscreen interface, camera input, stepper motors, custom PCB, and modular Python/PySide/QML application. The software separates drivers, services, domain logic, and QML views, allowing individual subsystems to be developed and tested independently.

Third, it develops a motion-control and backlash-compensation approach for low-cost open-loop mechanics. The system tracks per-axis backlash slack and applies compensation for automated moves and joystick movement.

Fourth, it implements an image-based calibration and workflow layer. Objective profiles, pixel-scale calibration, stage-scale calibration, backlash calibration, focus calibration, soft limits, and autofocus are integrated into the platform. These workflows demonstrate how the mechanical and software platform can be used as a calibrated microscope system.

\subsection{Thesis Structure}

The remainder of the thesis is structured as follows: It first reviews related work in digital microscopy, motorized stages, parametric fabrication, calibration, and open-source scientific hardware, then introduces the retrofit platform concept. The parametric mechanical adapter, the embedded hardware and software architecture, and the motion-control and backlash-compensation approach are described, followed by how the prototype has been evaluated. The thesis closes by discussing trade-offs, limitations, answering the research questions, and outlining future work.

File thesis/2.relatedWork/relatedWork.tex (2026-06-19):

\subsection{Vintage Microscope Interfaces and Retrofitting}

Many upright and inverted microscopes share a set of physical interfaces that are matching across manufacturers and generations. Focus is typically controlled through coarse and fine knobs, the sample is positioned through an XY stage or slide holder, illumination is adjusted separately, and image capture can often be added through an adapter or dedicated port. These interfaces are important for retrofitting because they provide mechanical access points that do not require modification of the optical path or the internal microscope frame.

A retrofit strategy differs from the design of a purpose-built automated microscope. Instead of constructing the optical and motion system as a single integrated device, it accepts the existing microscope as a constraint. The retrofit must therefore be mechanically reversible where possible and work with user-facing controls that were not designed for automation. This is both a limitation and an opportunity. It limits absolute precision and integration, but it also makes it possible to reuse optical instruments that would otherwise go to waste.

The OpenFlexure Microscope demonstrates that open-source hardware can support automated microscopy with low-cost components and 3D-printed structures \cite{collins2020openflexure}. RetroScope follows a related open-hardware motivation, but the design problem is different: it does not replace the microscope body with a printed microscope. Instead, it attaches an embedded system to an existing microscope and attempts to preserve the microscope as the optical core of the system.

\subsection{Digital Imaging in Microscopy}

Digital microscopy depends not only on acquiring images, but also on preserving enough metadata for later interpretation. Metadata quality is a known practical issue in biological imaging because image data often has to remain interpretable across software tools, laboratories, and later analysis steps \cite{linkert2010metadata}. The Open Microscopy Environment (OME) data model was developed to represent microscope image data and associated metadata in a structured way \cite{goldberg2005ome}. OME-TIFF combines TIFF image storage with OME metadata and is widely used as an interoperable format for biological imaging workflows \cite{omeTiffDocs}.

This matters for a retrofit platform because images captured from a motorized microscope are not isolated pictures. Their value depends on objective magnification, stage position, Z position, capture time, etc. A snapshot, focus stack, and tile scan should therefore be stored with metadata. RetroScope uses OME-TIFF for image captures and stores workflow-specific metadata so that captured data can be inspected in external tools such as ImageJ, Fiji, napari, and QuPath. ImageJ and Fiji are established open-source tools in biological image analysis \cite{schneider2012nih,schindelin2012fiji}, making interoperability with such ecosystems important for a practical microscope platform.

\subsection{Motorized Microscope Stages and Focus Control}

Motorized microscope stages and focus drives enable repeatable acquisition workflows that are impractical or tedious by hand. Commercial microscope systems often integrate closed-loop stages, encoders, vendor-specific control software, and precise motor drivers. Open software projects such as Micro-Manager provide a general control layer for microscope hardware and devices \cite{microManager2007,edelstein2014advanced}. Pycro-Manager extends this idea toward Python-controlled and reproducible microscope automation \cite{pinkard2021pycromanager}.

RetroScope operates at a different hardware level. The platform does not assume a commercial motorized stage. Instead, it must create motorized behavior by driving manual knobs. This makes the motion-control less precise because the system is separated from the actual sample position by the microscope mechanics, adapter gears, printed parts, and low-cost stepper motors. The benefit is that the approach can be applied to microscopes that were not designed for motorized control.

\subsection{Parametric CAD and Digital Fabrication}

Digital fabrication is central to RetroScope because it allows project-specific mechanical parts to be produced without industrial tooling. A parametric CAD model is particularly useful for retrofit work because the same design can be reused while dimensions are changed for another microscope body. In this thesis, parametric design is not only a convenience for modeling. It is part of the platform claim: if microscope control interfaces are structurally similar but geometrically different, then a retrofit adapter should expose the relevant geometric differences as editable parameters.

The main fabrication method used in this work is 3D printing. Making it possible to produce adapters, motor mounts, gears, brackets, and enclosure parts on accessible hardware, which directly supports the low-cost and reproducibility goals of the retrofit and allows a changed parameter to be reprinted without specialized tooling. This matches broader work on open labware and 3D-printable scientific equipment, where printed parts and shared design files are used to make laboratory hardware more accessible \cite{baden2015openlabware,zhang2013opensourceoptics}. The same accessibility underlies other open-hardware microscopes, like OpenFlexure, where printed structures replace machined parts \cite{collins2020openflexure}.

\subsection{Stepper Motors, Gear Reduction, and Backlash}

Low-cost geared stepper motors are attractive for retrofit systems because they are inexpensive, compact, and easy to drive. However, the gear train introduces backlash and makes manual movement difficult when the motor is energized. Comparing a 28BYJ-48 geared stepper motor with a direct-drive stepper identifies a key trade-off: the geared motor provides torque and resolution at low cost, but the internal gear reduction produces gear lock and mechanical slack. Backlash is especially problematic for image acquisition workflows. If a stage changes direction before capture, part of the commanded motor motion can be consumed by slack rather than actual displacement.

\subsection{Calibration in Digital Microscopy}

Calibration links image coordinates, optical magnification, and physical dimensions. Pixel-scale calibration makes measurements meaningful in units such as micrometers rather than pixels. Stage-scale calibration is additionally required for a motorized retrofit because motor steps must be converted into physical XY movement. Objective-specific parameters are also needed because magnification and numerical aperture affect field of view, depth of field, focus-stack spacing, and autofocus range.

An image-based calibration is needed to make open-loop hardware usable for workflows. On high-magnification objectives image-based calibration is difficult because the field of view is small and sensitive to even small movements. Therefore, the calibration process must be designed to be robust to the limitations of the hardware.

\subsection{Automated Microscopy Workflows}

Automated workflows such as autofocus, focus stacking, tile scanning, and calibrated measurement are common reasons for motorizing a microscope. Autofocus estimates an optimal Z position using an image sharpness measure. Comparative studies have evaluated different focus measures in brightfield microscopy \cite{pech2000diatom}, and algorithm choice is known to depend on sample, imaging modality, and computational constraints \cite{sun2004autofocusing}. Focus stacking combines multiple Z planes to increase apparent depth of field. Tile scanning captures adjacent fields of view and combines or stores them as larger mosaics. Image-stitching methods can optimize alignment into an seamless capture \cite{preibisch2009globally}.

In this thesis these workflows are treated as validation of the platform rather than new algorithmic contributions. The question is not whether a new autofocus or stitching algorithm has been invented. The question is whether the retrofit mechanics, calibration, and embedded software are good enough to support these workflows on a vintage microscope.

\subsection{Existing Microscope Automation Systems}

Existing automation systems can be grouped roughly into commercial integrated platforms, open software controllers, and open hardware microscopes. Commercial systems provide high integration and precision, but they are expensive and often vendor-specific. Open software systems such as Micro-Manager and Pycro-Manager make microscope control more flexible and reproducible when compatible hardware is available \cite{edelstein2014advanced,pinkard2021pycromanager}. Low-cost microscopy projects such as Foldscope demonstrate how simplified, accessible fabrication can broaden access to optical microscopy \cite{cybulski2014foldscope}. Open hardware platforms such as OpenFlexure extend this accessibility argument toward motorized microscopy built from accessible components \cite{collins2020openflexure}.

This thesis occupies a complementary position. It is not a general hardware-control layer for commercial microscope devices, and it is not a full microscope built from scratch. It is a retrofit platform for existing microscopes whose optical and mechanical core remains in place. This makes adaptability to existing physical interfaces the central design concern.

\subsection{Research Gap}

The related work shows approaches for microscope control, microscopy image metadata, open-source image analysis, and motorized microscopes. However, these approaches do not fully address the specific problem of turning existing vintage microscopes into reusable automated platforms. Commercial automation systems usually assume compatible motorized hardware, while open hardware microscopes often solve the problem by building a new microscope structure. A retrofit has to solve a different problem: it must find a usable interface on an already existing instrument.

This makes universal adaptation a central research gap. In this context, universal does not mean that one fixed adapter can fit every microscope. Vintage microscopes differ in knob diameters, axis spacing, available mounting points, camera connections, and mechanical clearances. Nevertheless, many of them expose similar functional interfaces: a focus drive, XY-stage controls, an optical or camera path, and a stable frame or base. The research challenge is therefore to identify these recurring access points and represent their differences through adaptable parameters, so that the same platform concept can be transferred to another microscope body without redesigning the electronics, software, calibration process, and workflows from scratch.

The gap addressed by this thesis is the combination of these ideas in a retrofit platform for existing vintage microscopes. The platform must bridge human-facing microscope mechanics and software-controlled capturing while remaining low-cost and adaptable. The contribution therefore lies in treating the microscope interface itself as a configurable layer and integrating parametric mechanical adaptation, embedded hardware, open-loop motion compensation, and image-based calibration into one working retrofit artifact.

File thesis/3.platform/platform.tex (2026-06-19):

\subsection{Shared Physical Control Interfaces of Microscopes}

The platform concept starts from a simple observation: many microscopes expose comparable physical controls even when their internal mechanics differs. A human operator commonly interacts with a microscope through focus knobs, XY-stage knobs, objective selection, illumination controls, and an observation or camera path. These interfaces are designed for manual work, but they also provide a relatively stable abstraction for a retrofit system. Instead of redesigning the optical path, the retrofit can attach to the same controls that the operator would normally use.

\input{figures/fig_shared_interface}

This observation is important because it changes the design goal from building a universal mechanical replacement to building an adaptable mechanical interface. The retrofit does not need to know the internal details of the stage or focus drive. It needs to know where the user-facing controls are, how they rotate, how much torque is required, how much slack exists, and how motor motion maps to optical motion. These properties can be measured or calibrated for a particular microscope body.

Figure~\ref{fig:shared-interface} illustrates this shared layout across microscopes from several manufacturers and price classes, from low-cost educational instruments such as the Labtron LBM-A14 to a research-grade ZEISS Axioscope 5. Despite large differences in price, optics, and internal construction, each instrument presents the same operator-facing controls. It is precisely this commonality that makes a parameter-driven retrofit feasible, because the platform can target a recurring control layout rather than a single microscope model.

\subsection{Driving Existing Knobs Instead of Replacing Microscope Mechanics}

Driving existing microscope controls instead of replacing the microscope mechanics reduces invasiveness and preserves the optical instrument as the core of the system. The XY stage remains the microscope's own stage, and the focus axis remains the microscope's own focus mechanism. Motors and adapters are added externally to rotate the controls that would otherwise be rotated by hand.

The advantage of this approach is reversibility and compatibility. It avoids machining or redesigning the internal stage and focus mechanism. It also keeps the retrofit concept understandable: a motor turns the same knob that the user would turn. The disadvantage is that the retrofit inherits all imperfections of the original mechanical path and adds new imperfections from the adapter. Backlash, 3d-print flex, friction, and looseness in the existing controls all become part of the motion system.

This trade-off defines the platform. Is not a precision stage bolted onto a microscope. It is an embedded control layer attached to manual controls. The platform must therefore rely on calibration and software compensation to make the resulting motion useful.

\subsection{Platform Overview}

RetroScope consists of four tightly connected subsystems. The mechanical subsystem provides adapters, motor mounts, gear couplings, brackets, supports, and enclosure parts. The embedded electronics subsystem connects the Raspberry Pi, touchscreen, motors, joystick, rotary encoder, buttons, camera capture device, and custom PCB. The software subsystem implements hardware drivers, services, domain logic, and the QML user interface. The calibration and workflow subsystem turns the mechanical and electronic platform into a usable microscope application.

The system is operated primarily through a touchscreen interface. The QML interface contains views for live imaging, gallery browsing, measurement, automation, and settings. Physical controls remain important: a joystick controls XY motion, a rotary encoder controls focus, buttons trigger assigned actions, and an endstop protects the focus axis. Camera input provides a live preview and a frame-analysis stream for histogram, focus scoring, calibration support, and objective-change detection.

The platform supports snapshots, calibrated measurement, autofocus, focus stacking, tile scanning, gallery management, and REST-based access to captures and selected actions. Focus stacking and tile scanning workflows are not independent features added after the fact. They require calibrated objective data, motor control, and camera capture to work together and evaluate the platform as a whole. These workflows are therefore important demonstrations of the platform's capabilities and design.

\begin{figure}[H]
    \centering
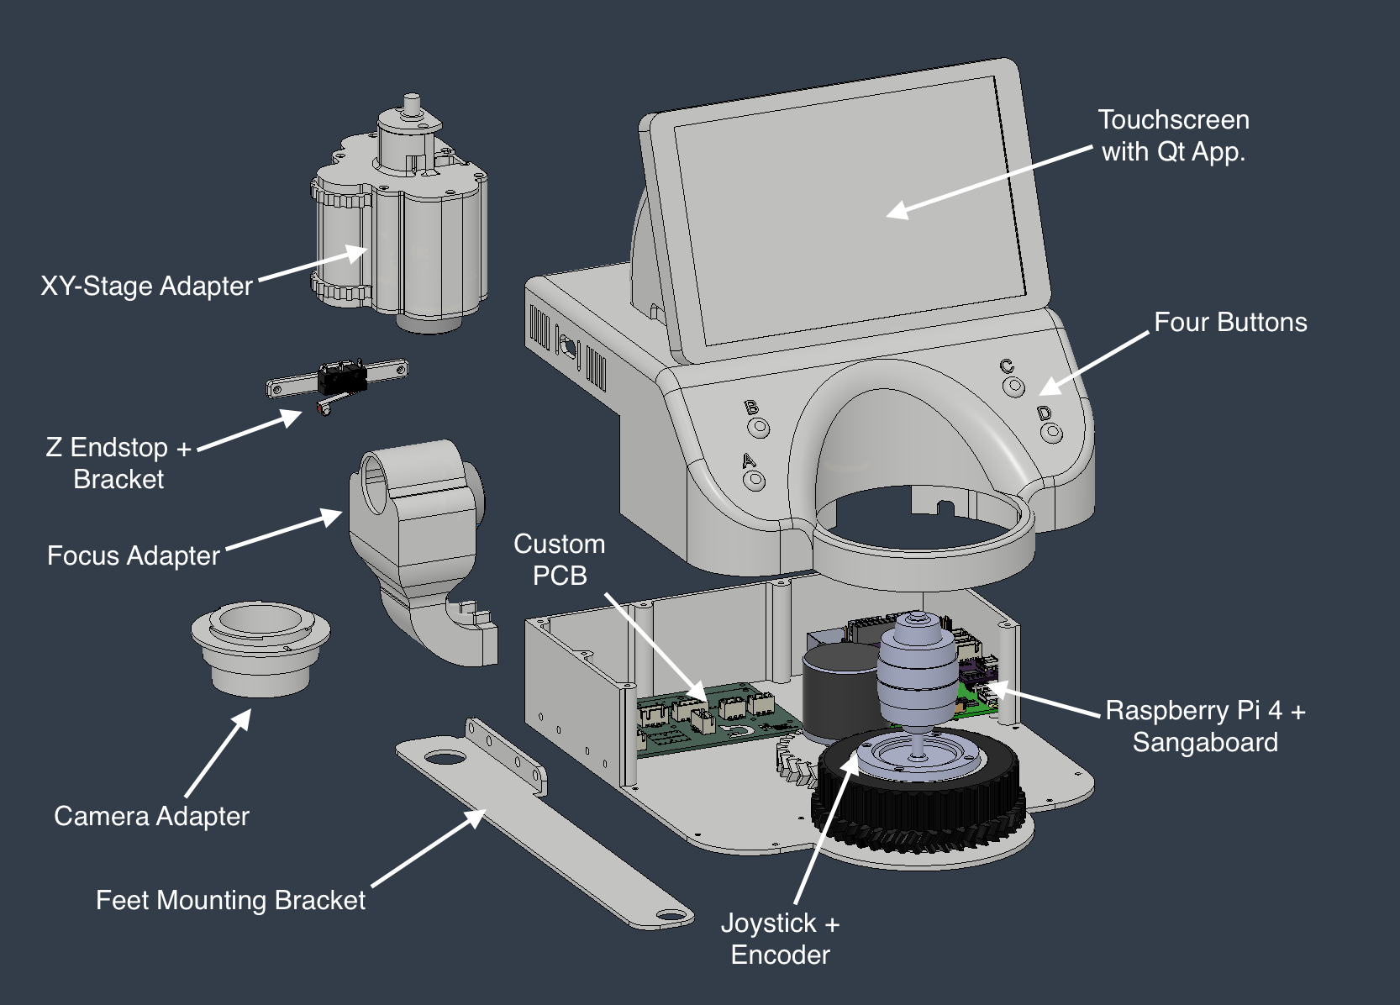
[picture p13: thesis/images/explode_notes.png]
    
    \caption[Exploded view of retrofit components]{Exploded render of the RetroScope prototype. The view separates the printed enclosure, joystick and encoder assembly, Raspberry Pi and Sangaboard electronics, custom PCB, feet mounting bracket, focus adapter, Z endstop bracket, XY-stage adapter, and camera adapter.}
    \label{fig:explode-diagram}
\end{figure}

\subsection{Open-Source Platform Artifacts}

RetroScope is intended as an open platform rather than a single prototype. The repository contains the Python/PySide/QML application, test suite, deployment scripts, README documentation, REST API demo notebook, KiCad~\cite{kicad} PCB files, Gerber outputs, and the parametric Autodesk Fusion~\cite{autodeskFusion} model. This collection is important because a retrofit platform cannot be reproduced from software alone. The physical adapter, electronics, and calibration process are part of the artifact.

The open-source release also supports extension. The software architecture is split into drivers, services, domain modules, bridge classes, and QML views. The hardware release includes PCB and CAD artifacts. The documentation describes setup, operation, and current limitations. Together, these artifacts allow the work to be inspected, modified, and adapted to other microscope bodies.

\newpage

Figure~\ref{fig:platform-overview} summarises how these subsystems stack on top of the unmodified
microscope. The retrofit adds mechanical, electronic, software, and calibration/workflow subsystems on top of the  vintage microscope, driving its existing focus and stage controls rather than replacing the optical instrument.

\input{figures/fig_platform_overview}

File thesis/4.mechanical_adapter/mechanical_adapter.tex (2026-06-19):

\subsection{Mechanical Retrofit Challenge}

The mechanical design problem is constrained by the existing microscope. The retrofit must attach to a microscope body that was not designed for external motors, must align with existing knobs and axes, and must avoid interfering with normal optical operation. It must also be printable and adjustable enough to be built without specialized workshop equipment. These constraints make the mechanical adapter one of the main contributions of the platform.

The prototype development began by understanding the geometry of the development microscope, a Nikon Optiphot 66 (a vintage microscope from the 1980s). It was 3D scanned and measured to determine the locations of the focus axis, XY stage, and mounting points. It also needed maintenance such as replacement of lubricants and regreasing of the XY handle to ensure smooth manual operation.

\begin{figure}[H]
    \centering
    \begin{subfigure}[t]{0.49\linewidth}
        \centering
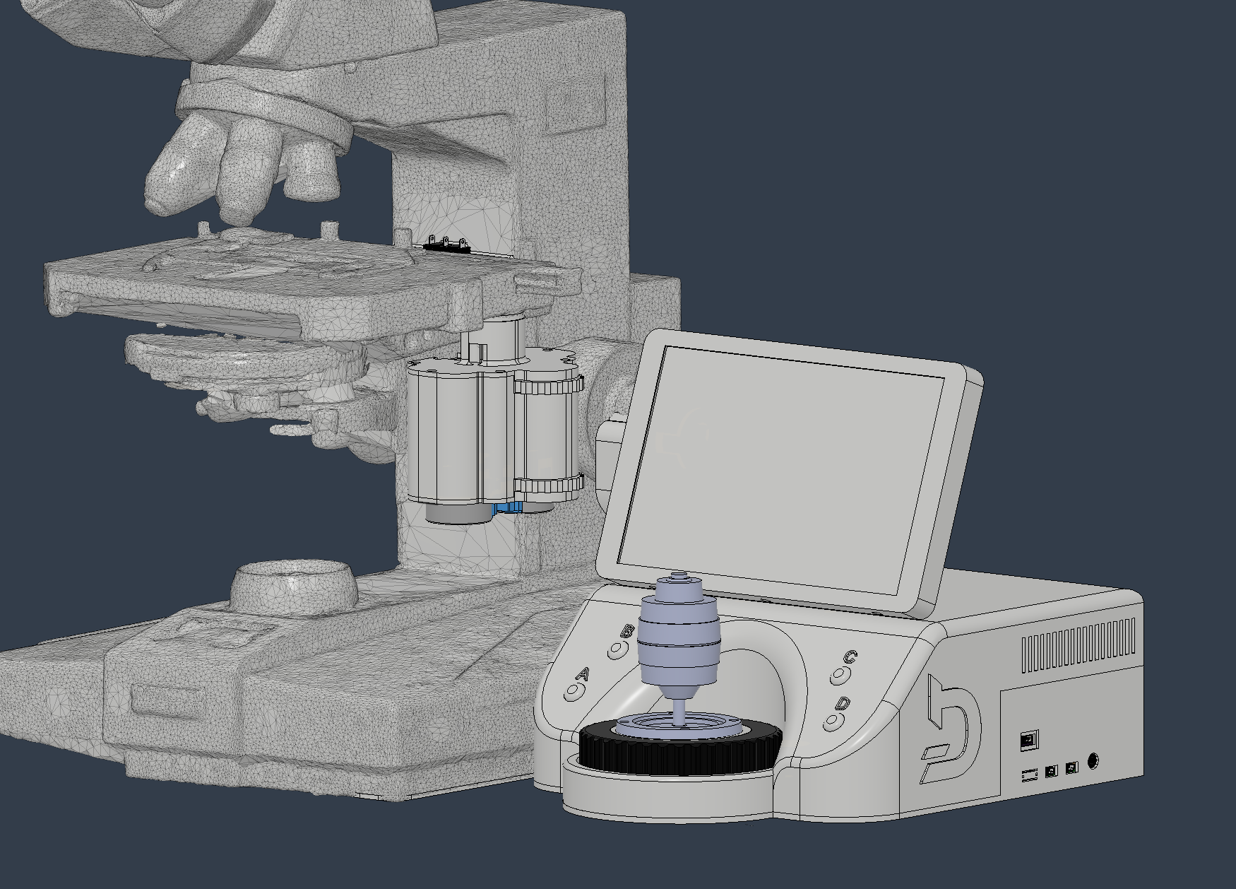
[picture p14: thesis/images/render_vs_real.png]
        
        \caption{CAD render incl. 3D scan of the baseline microscope.}
    \end{subfigure}\hfill
    \begin{subfigure}[t]{0.49\linewidth}
        \centering
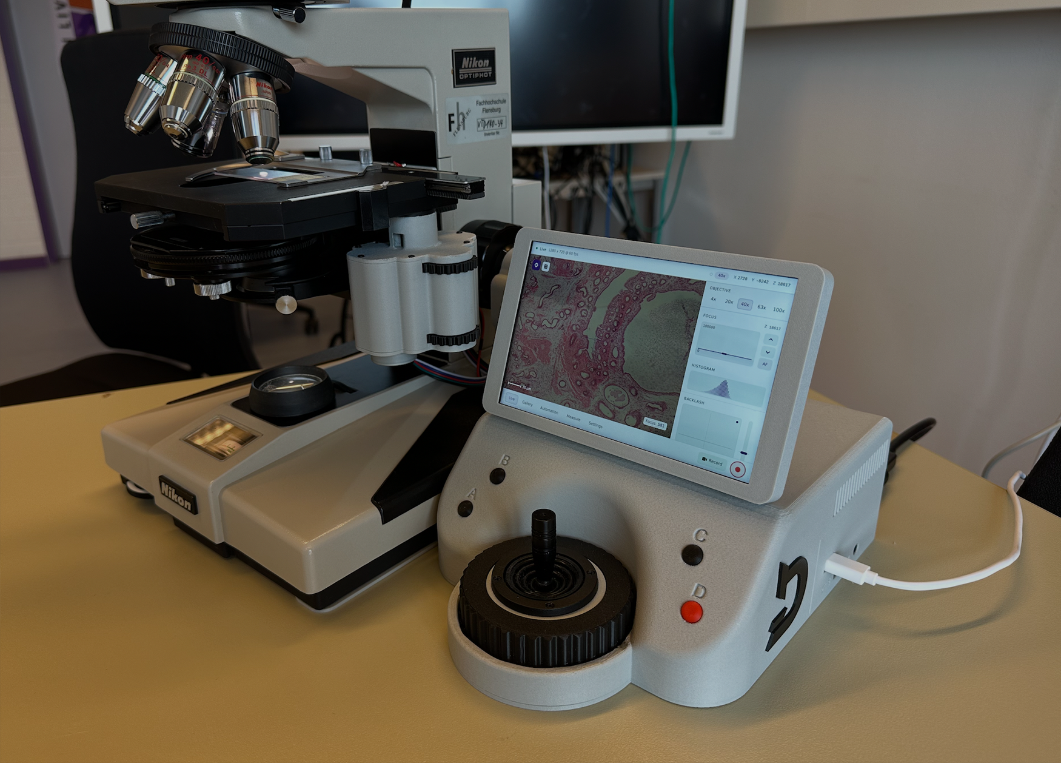
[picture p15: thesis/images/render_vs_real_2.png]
        
        \caption{Assembled prototype attached to the Nikon Optiphot 66.}
    \end{subfigure}
    \caption[Rendered and assembled prototype]{Comparison between the design model and the physical prototype. The left image shows the retrofit render aligned with the 3D scan of the Nikon Optiphot 66 baseline microscope. The right image shows the fully assembled RetroScope prototype attached to the same microscope body.}
    \label{fig:platform-render-vs-real}
\end{figure}

The retrofit has to balance attachment strength, reversibility, printability, and usability. Parts must be rigid enough to avoid flex during motion, but must also be easy to print and assemble. Knob adapters must transfer torque without damaging the microscope. Motor mounts must keep the gears stable. The user interface enclosure must contain display, electronics, and manual controls while still fitting next to the microscope.

\subsection{Fusion Parametric Model}

The mechanical design is captured in a parametric Autodesk Fusion model. The exported model in the repository is stored as a Fusion archive and includes several custom parameters that control important geometry. Examples include connector-hole positions and connector-hole radii for the microscope feet, focus-axis height, focus-axis radius, Z-assembly height, Z-assembly offsets, and XY-assembly offsets.

\begin{figure}[H]
    \centering
    \begin{subfigure}[t]{0.49\linewidth}
        \centering
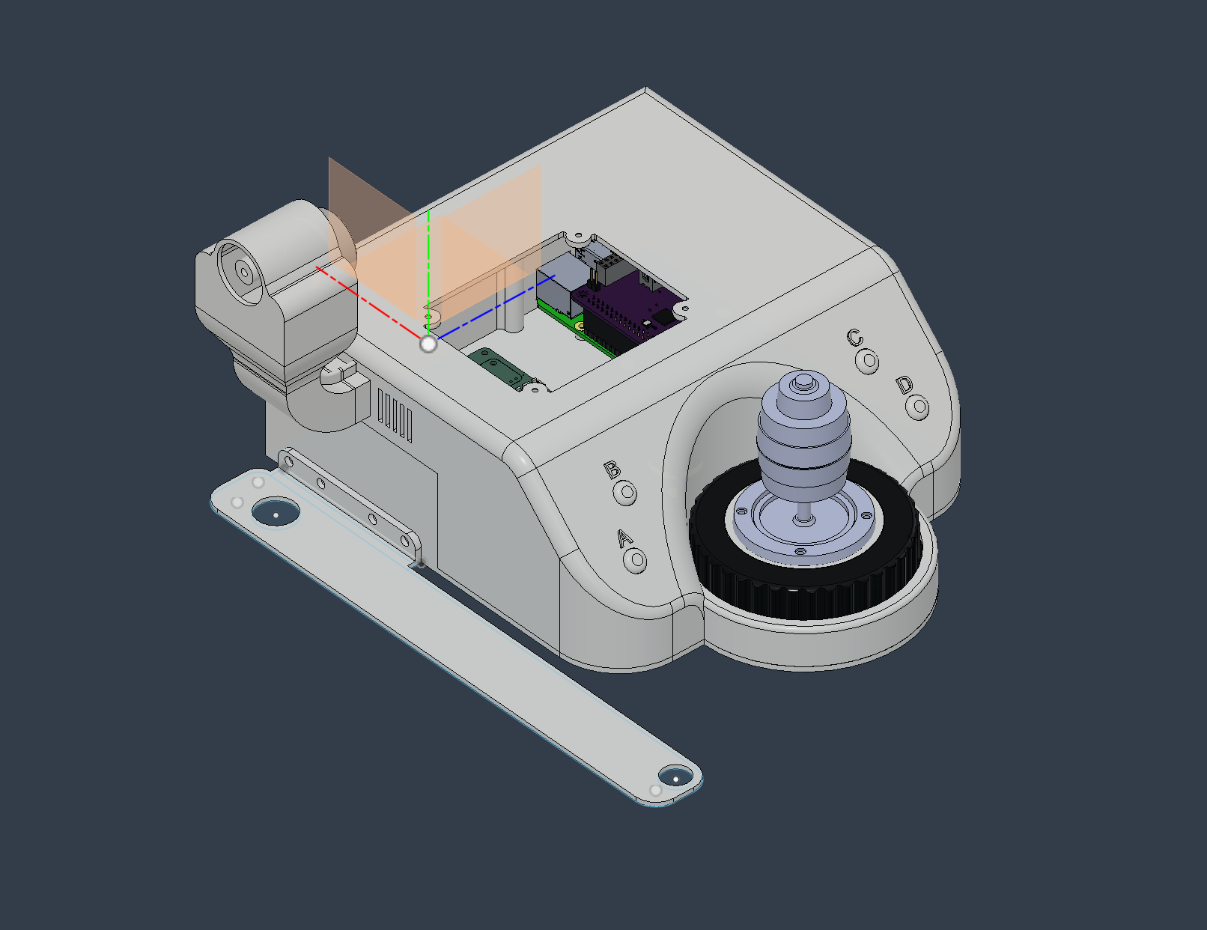
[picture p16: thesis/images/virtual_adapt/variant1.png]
        
        \caption{Baseline (Nikon Optiphot 66)}
    \end{subfigure}\hfill
    \begin{subfigure}[t]{0.49\linewidth}
        \centering
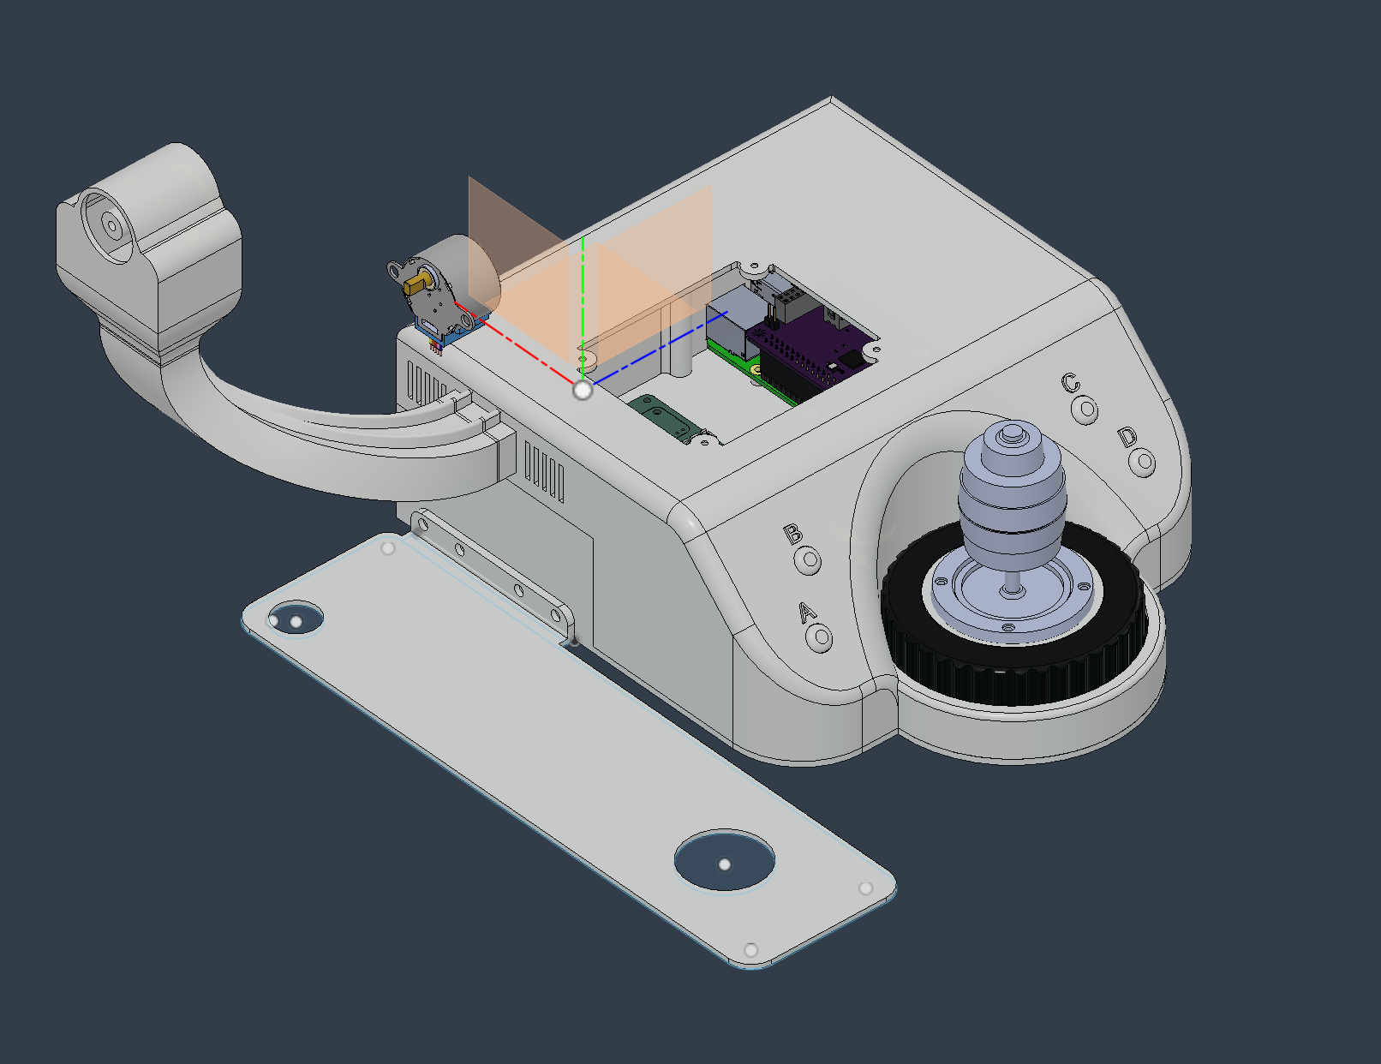
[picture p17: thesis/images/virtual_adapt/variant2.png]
        
        \caption{Virtual variant}
    \end{subfigure}
    \caption[Parametric mechanical adapter render]{Render of the parametric mechanical adapter from the Fusion model, showing the baseline enclosure and a virtual variant generated by changing model parameters.}
    \label{fig:teaser-virtual-adapt}
\end{figure}

The purpose of these parameters is to separate design intent from microscope-specific dimensions. If another microscope has a different focus-axis height or different mounting geometry, the model should be adjusted by changing parameters instead of rebuilding the assembly manually. This makes the model adaptable rather than specifically designed for the Nikon Optiphot 66.

\begin{table}[H]
    \centering
    \caption[Fusion model parameters]{Example parameters of the parametric Fusion model and their physical meaning.}
    \label{tab:fusion}
    \begin{tabular}{@{}l c L{6.2cm}@{}}
        \toprule
        \textbf{Parameter} & \textbf{Value} & \textbf{Meaning} \\
        \midrule
        \texttt{connector\_hole\_front\_x/y} & 10\,mm /10\,mm & X/Y position of the front hole for the microscope feet \\
        \texttt{connector\_hole\_back\_x/y}  & 14.5\,mm /25.5\,mm & X/Y position of the rear hole for the microscope feet \\
        \texttt{connector\_hole\_front/back\_radius} & 13\,mm & Front/Rear hole radius for the feet \\
        \texttt{focus\_axis\_z}      & 137\,mm & Height of the focus axis \\
        \texttt{focus\_axis\_radius} & 17\,mm  & Focus-knob coupling radius \\
        \texttt{z\_assembly\_height} & 137\,mm & Height of the Z (focus) sub-assembly \\
        \texttt{z\_assembly\_x\_offset} / \texttt{z\_offset} & 0\,mm & Z sub-assembly position offsets \\
        \texttt{xy\_assembly\_offset\_x/y/z} & 0\,mm & XY sub-assembly position offsets \\
        \bottomrule
    \end{tabular}
\end{table}

\subsection{Focus and XY-Stage Adapter Design}

The retrofit drives both the focus mechanism and the XY stage through the existing controls. For the XY stage, the adapter must couple motors to the stage handle while preserving the relationship between X and Y knobs. For the focus axis, the adapter must move the focus reliably while also respecting the risk of crashing an objective into the stage or sample.

The XY-stage drive required a dedicated compact gearbox rather than a simple direct motor-to-knob connection. Generally, the X and Y stage controls are implemented as two differently sized knobs stacked on top of each other. This geometry had to be preserved because it is a common manual-control arrangement and because replacing the complete stage drive would reduce compatibility with other microscope bodies. The adapter therefore places printed gears on top of the existing knobs and uses an external gear train to interface these gears with the motors. Because the available space around the knob stack was limited, the motors and gear supports had to be located below the knobs rather than beside them at the same height.

The selected XY-stage gear relation uses a 12-tooth motor gear driving a 24-tooth knob gear, resulting in a 1:2 reduction at the microscope control. A 12:12 relation was also considered because a 1:1 interface could reduce backlash introduced by the printed gears. However, the 12:24 relation doubles the available output torque and the effective motor-step resolution at the stage knob. The final adapter therefore keeps the 1:2 ratio as a trade-off: compared with a 1:1 relation, it can increase the backlash contribution of the gear path, but it improves torque margin and motion granularity for the low-cost motor drive.

\begin{figure}[H]
    \centering
    \begin{subfigure}[t]{0.31\linewidth}
        \centering
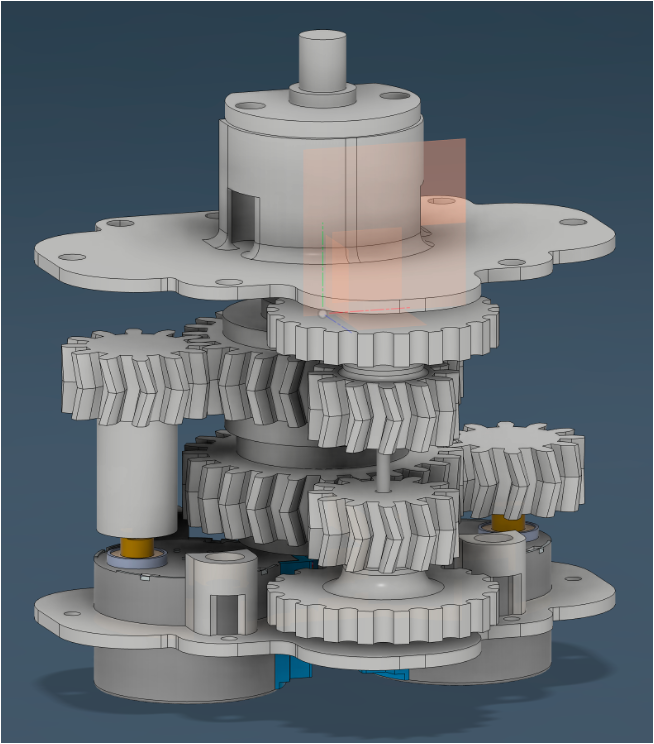
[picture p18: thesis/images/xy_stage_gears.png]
        
        \caption{The exposed gearbox of the XY-stage adapter.}
    \end{subfigure}\hfill
    \begin{subfigure}[t]{0.31\linewidth}
        \centering
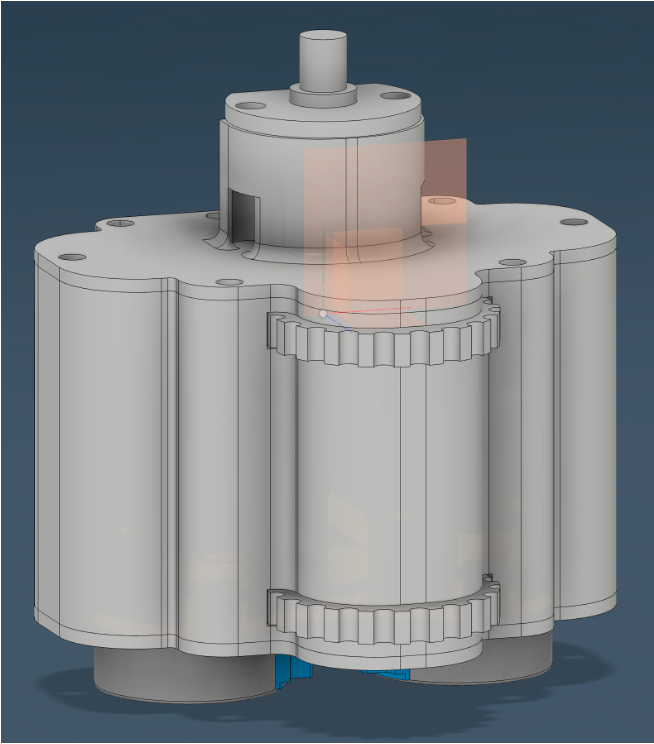
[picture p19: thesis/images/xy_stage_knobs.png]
        
        \caption{The full enclosure and protruding knobs of the XY-stage adapter.}
    \end{subfigure}\hfill
    \begin{subfigure}[t]{0.31\linewidth}
        \centering
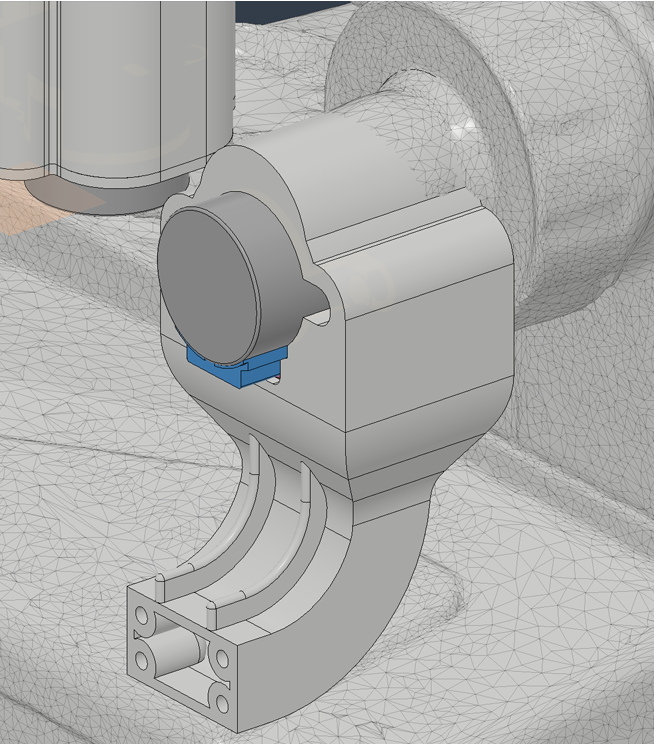
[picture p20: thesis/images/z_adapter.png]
        
        \caption{The focus adapter for the Z-axis.}
    \end{subfigure}
    \caption[XY-stage and Z-axis adapters]{Renders of the XY-stage and Z-axis adapters.}
    \label{fig:xy-z-adapters}
\end{figure}

For a rigid connection between the printed gears and the original knob, a set screw can pass through the printed gear into the original knob so that both are locked together. For less invasive installation, the same geometry can also be used as a press fit when the available friction is sufficient for the expected torque. In addition to the motor gears, the gearbox includes manual drive gears connected to new external knobs protruding from the XY-stage assembly. These knobs allow the stage to be turned by hand when the motors are unenergized and also provide a visible indication of motion during motorized operation.

The Z-axis adapter directly connects the motor shaft to the microscope's fine-focus axle. For this connection, the original fine-focus knob was removed and replaced by a printed shaft adapter that locks the motor shaft and fine-focus axle together with a set screw. Because the fine-focus axle is mechanically coupled to the microscope's focus mechanism, driving it moves the complete Z axis within the physical travel limits of the microscope. The coarse-focus knobs therefore remain untouched, which preserves the original coarse adjustment and reduces the invasiveness of the retrofit.

This direct fine-focus coupling also means that larger Z movements require comparatively long motor runs, because the fine-focus mechanism is designed for small manual adjustments. The printed Z adapter is connected to the surrounding structure by a cable-guiding arm, as shown in Figure~\ref{fig:xy-z-adapters}c. This arm is part of the parametric model and extends dynamically from the models parameters, allowing the focus adapter geometry to follow the configured microscope dimensions.

The enclosure became part of the mechanical design. The main body holds the Raspberry Pi, motor controller, joystick base, PCB, and wiring. The display casing holds the touchscreen. Additional buttons and the focus knob are placed so that the operator can use the system as a microscope control station rather than only as an automated backend. The z-axis adapter is directly mounted to the enclosure, routing the cables and providing a stable connection to the focus mechanism. The XY-stage adapter is only connected by wires, because it is connected to the micrscope stage, which is moving during operation and therefore cannot be rigidly attached to the enclosure.

\subsection{3D-Printing and Material Considerations}

The prototype uses 3D-printed parts, from PETG and ABS-GF filaments. Printing allowed rapid iteration, which is one of the reasons additive manufacturing is widely used in open labware and low-cost scientific hardware development \cite{baden2015openlabware,zhang2013opensourceoptics}. At the same time, it also introduced tolerances, friction differences, and flex. Threaded inserts were used where repeated assembly or stronger threads were required. Some printed features were adjusted for usability, such as grip indentations on the focus handle and a thinner display bezel to improve access to the touchscreen edges.

Material choice is a trade-off. PETG is easy to print and useful for prototypes, but it may not provide sufficient stiffness or heat resistance for all parts. ABS and glass-fiber-reinforced materials can improve mechanical properties, but they increase printing difficulty. For a retrofit platform, the "best" material also depends on the available printer, the microscope geometry, and the expected mechanical loads.

\begin{table}[H]
    \centering
    \caption[3D-printing configuration]{3D-printing configuration for the prototype parts.}
    \label{tab:print}
    \begin{tabular}{@{}l L{7.8cm}@{}}
        \toprule
        \textbf{Setting} & \textbf{Value} \\
        \midrule
        Materials       & PETG (Gears, Buttons, ...) and ABS-GF (Enclosure parts) \\
        Nozzle diameter & 0.4 mm \\
        Layer height    & 0.20 mm \\
        Infill          & 30\% \\
        Perimeters / walls & 2 \\
        \bottomrule
    \end{tabular}
\end{table}

\begin{figure}[H]
    \centering
    \begin{subfigure}[t]{0.31\linewidth}
        \centering
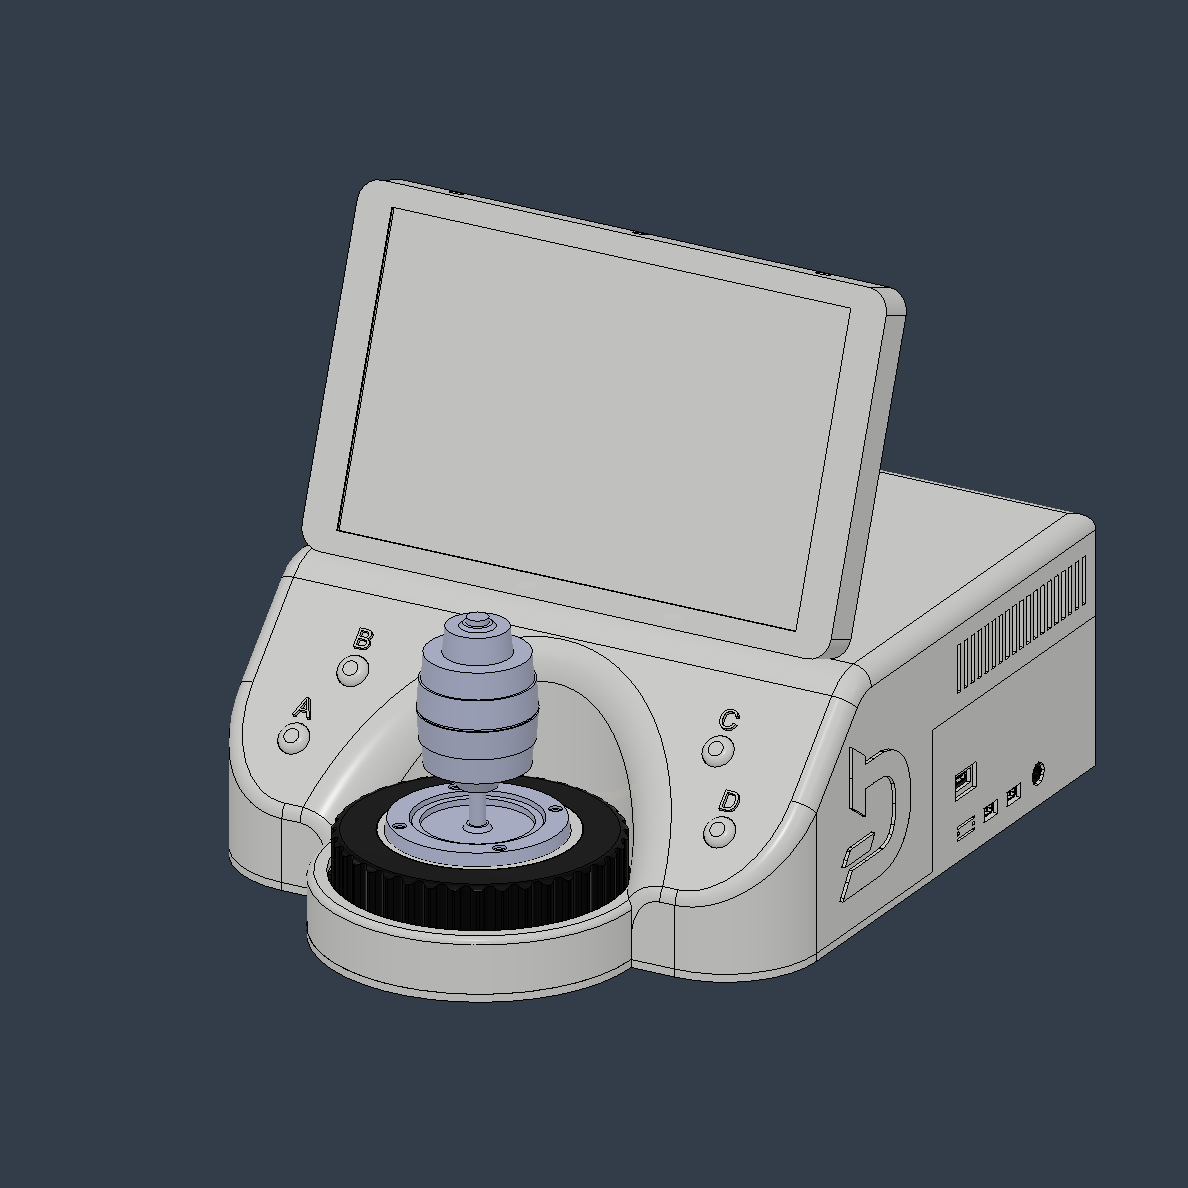
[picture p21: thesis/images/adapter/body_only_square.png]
        
        \caption{Enclosure with touchscreen and controls.}
    \end{subfigure}\hfill
    \begin{subfigure}[t]{0.31\linewidth}
        \centering
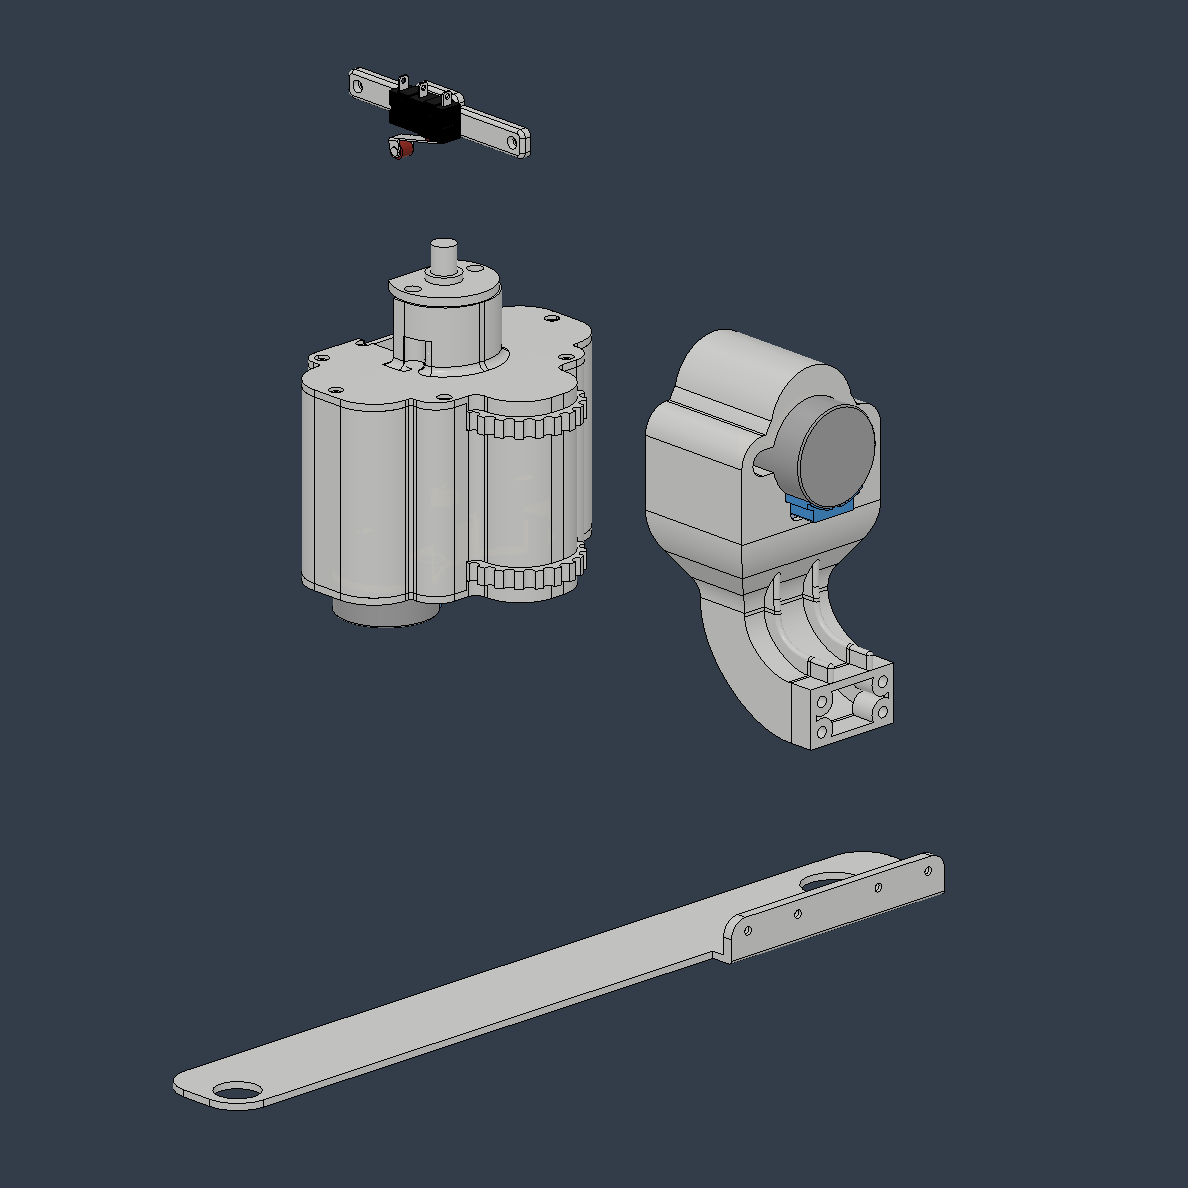
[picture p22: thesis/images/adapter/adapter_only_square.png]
        
        \caption{Parametric adapter assemblies.}
    \end{subfigure}\hfill
    \begin{subfigure}[t]{0.31\linewidth}
        \centering
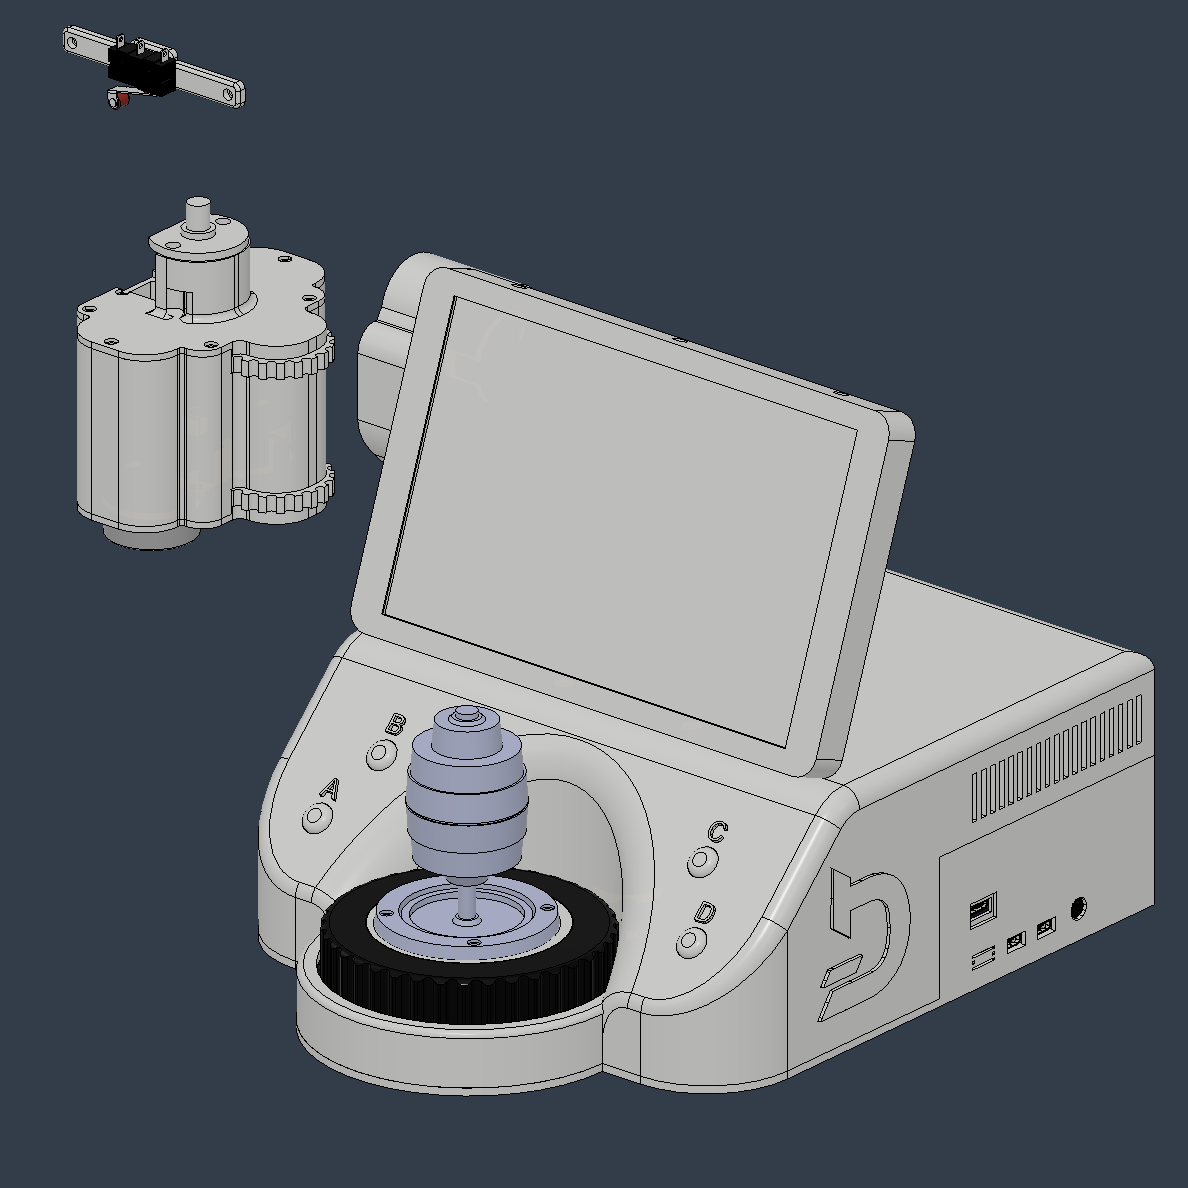
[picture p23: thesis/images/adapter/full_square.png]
        
        \caption{Adapters fitted to the enclosure.}
    \end{subfigure}
    \caption[Parametric mechanical adapter render]{Render of the parametric mechanical adapter from the Fusion model: enclosure only,
    retrofit assemblies, and fitted full configuration.}
    \label{fig:adapter-render}
\end{figure}

\subsection{Camera Mount Adapter}

The Nikon Optiphot 66 used as the baseline microscope can be connected to a camera through a Nikon PFX manual photomicrography attachment. In its original use, this attachment provides a mechanical camera interface and shutter path for photographic capture. For the retrofit, however, keeping this attachment in the optical chain was not ideal. The available PFX unit added an additional lens between the microscope body and the camera, which produced an additional magnification of the slide image on the camera sensor and therefore reduced the captured field of view.

\begin{figure}[H]
    \centering
    \begin{subfigure}[t]{0.31\linewidth}
        \centering
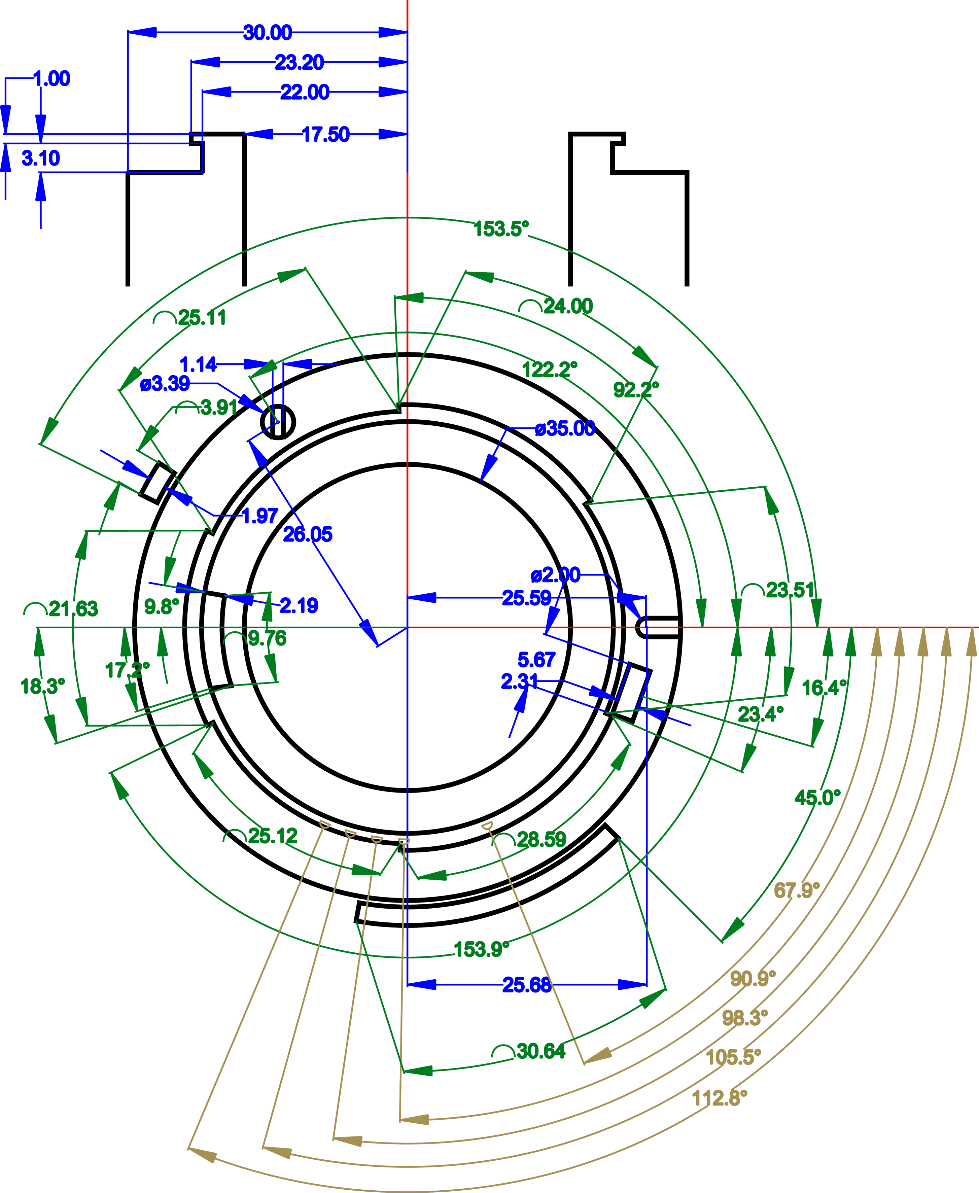
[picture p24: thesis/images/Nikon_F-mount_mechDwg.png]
        
        \caption{Nikon F-mount reference dimensions \cite{img:nikonFMountDrawing,edmundLensMounts}.}
    \end{subfigure}\hfill
    \begin{subfigure}[t]{0.31\linewidth}
        \centering
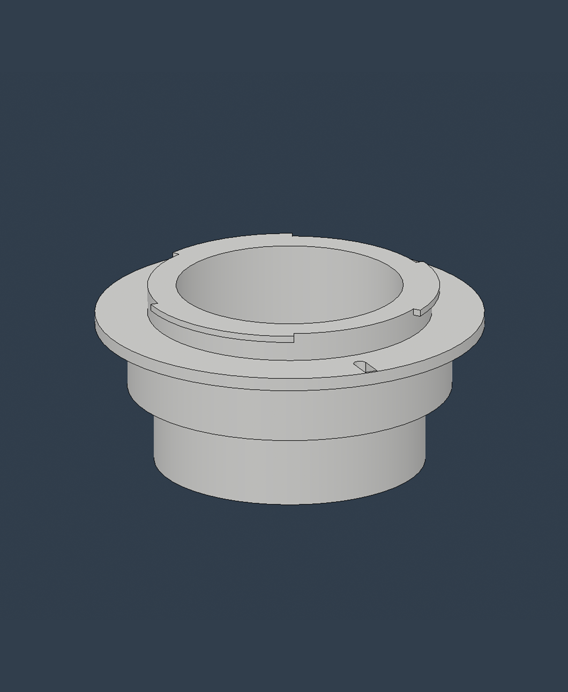
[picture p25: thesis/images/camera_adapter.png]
        
        \caption{Adapter model derived from the F-mount and PFX geometry.}
    \end{subfigure}\hfill
    \begin{subfigure}[t]{0.31\linewidth}
        \centering
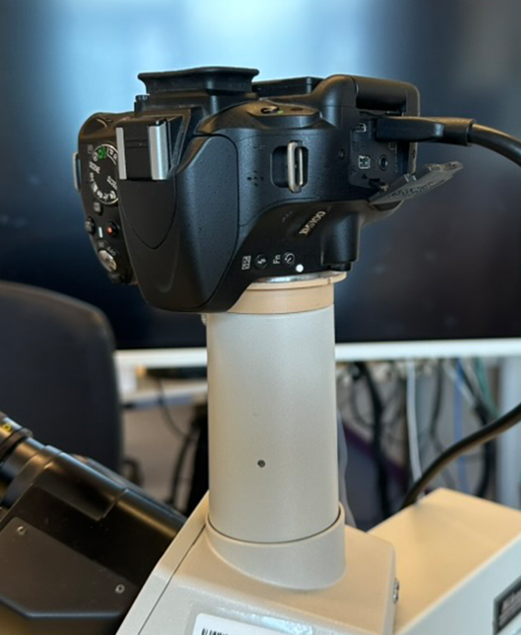
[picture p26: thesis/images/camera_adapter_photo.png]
        
        \caption{Camera attached to the microscope through the printed adapter.}
    \end{subfigure}
    \caption[Camera mount adapter]{Camera mount adapter for replacing the Nikon PFX attachment in the prototype. The left image shows the Nikon F-mount reference dimensions, the middle image shows the CAD model of the printed adapter, and the right image shows the camera mounted directly to the microscope body through the printed adapter.}
    \label{fig:camera-adapter}
\end{figure}

A dedicated 3D-printed camera adapter was therefore designed to replace the PFX attachment for the prototype. The adapter connects directly to the microscope port on the microscope side and provides a Nikon F-mount interface on the camera side. The F-mount geometry was modelled from reference mount dimensions \cite{img:nikonFMountDrawing,edmundLensMounts}, while the microscope-side interface was based on the measured geometry of the microscope and the removed PFX attachment. This bypasses the additional PFX optical element and enlarges the field of view seen by the camera. This adapter is only required for the specific microscope body and camera path used in the prototype. Other microscopes may already provide a suitable camera attachment or may require a different adapter geometry.

\subsection{Adaptability and Mechanical Limitations}

The mechanical adapter supports adaptability through parameterization, but it does not remove the need for physical validation. A new microscope body still requires measuring control locations, checking available mounting points, verifying travel limits, printing test parts, and calibrating motion. The platform therefore provides a reusable design strategy rather than a guarantee that one printed part fits every microscope.

The most important mechanical limitations are backlash, flex, friction, print tolerances, and the absence of direct position feedback. These limitations directly shaped later software design. The calibration process measures pixel scale, stage scale, and backlash. The motion engine tracks slack and compensates for it.

In this sense, the mechanical adapter and the software are not separate contributions. The mechanical design makes motorization possible, and the software makes the imperfect mechanics usable enough for e.g. automated imaging workflows.

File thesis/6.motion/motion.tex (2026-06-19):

\subsection{Motion-Control Pipeline}

The motion-control pipeline translates user or workflow inputs into motor commands while enforcing safety and compensation logic. Motion requests can originate from, e.g., the touch interface, joystick, rotary encoder, autofocus routine, focus stacker, or tile scanner. These requests are routed through the motion controller rather than being sent directly to the motor driver.

The motion controller maintains the current logical position in motor steps, applies endstop and soft-limit checks, converts calibrated image distances into stage steps where needed, and plans backlash compensation. It then sends relative moves to the Sangaboard driver, which ultimately controls the stepper motor. Some moves are fire-and-forget for responsive manual control, while other moves are blocking because an workflow must wait until physical motion is complete before capturing an image.

This structure is necessary because the same motor axes are shared by manual and automated behavior. A focus move from the encoder, an autofocus sweep, and a focus-stack step all operate on the Z axis, but they have different timing requirements. Similarly, joystick movement should feel responsive, while tile scanning requires predictable stage positions.

\subsection{Manual Motion Through Touch UI, Joystick, and Encoder}

Manual XY motion is controlled primarily through the joystick. The joystick provides two analog axes through the ADS1115 ADC. The software applies deadzone, sensitivity, optional axis swapping/inversion. The requested speed is interpreted in image-space terms through the active objective profile and stage calibration, so that the joystick behavior relates to the visible field of view rather than only to raw motor steps. The system accumulates joystick movement and dispatches motor commands at a fixed interval, reducing the high-rate stream of tiny relative moves that caused jitter.

Focus movement is controlled through a rotary encoder. During depth-of-field calibration, the encoder uses a fixed fine Z step so that the operator can make controlled adjustments. The calibrated death-of-field steps are then stored in the objective profile. During operation, the encoder uses the step size from the active objective profile so that the manual focus behavior is consistent between objectives regardless of there magnifications. The system also exposes manual touch controls and tap-to-move behavior in the live view, where image-pixel offsets are converted into stage steps using the active objective scale and calibrated stage scale.

Blocking moves are used when the software must know that motion has completed. Autofocus, focus stacking, tile scanning, stage calibration, and backlash measurement all depend on a stable image after movement. If a capture is taken while the motor is still moving or while commands overlap, the resulting image can be blurred or spatially inconsistent.

\subsection{Stage Scale and Axis Asymmetry}

In a motorized retrofit, one motor step is not automatically equal to a known physical distance at the sample. The mapping depends on the motor, gear ratio, microscope stage mechanism, adapter geometry, and axis-specific friction or play. The platform therefore stores separate stage-scale values for X and Y in micrometers per motor step.

Axis asymmetry is expected. The configuration stores separate X and Y stage scales and separate X and Y backlash values. Tile-scan planning uses these calibrated stage scales independently, because a single stage conversion would place tiles too far apart or too close together on at least one axis.

\subsection{Software Backlash Compensation Model}

The 28BYJ-48 geared stepper motor was selected because it is inexpensive and accessible, but its internal gear reduction is central to the motion behavior of the prototype. Stepper motors are commonly used for open-loop positioning, but their actual positional reliability depends on load, missed steps, drive electronics, and mechanical transmission \cite{acarnley2002stepping}. The 1:64 internal reduction causes high resistance to manual rotation and backlash in the gear train. The motor's low cost therefore comes with mechanical disadvantages that must be addressed at the system level.

Backlash compensation is implemented as a per-axis hysteresis model. For each axis $i$, the controller stores a configured backlash width $b_i$ in motor steps and an estimated slack state $s_i$ with
\[
    -\frac{b_i}{2} \leq s_i \leq \frac{b_i}{2}
\]
The slack state represents where the drive train is currently located inside the backlash band. A value near $+b_i/2$ means that the axis is loaded in the positive direction, while a value near $-b_i/2$ means that it is loaded in the negative direction. When a compensated movement $d_i$ is requested, the controller computes a single motor command that contains both the requested displacement and the slack take-up:
\[
    p_i = \operatorname{sign}(d_i)\frac{b_i}{2} - s_i,
    \qquad
    m_i = d_i + p_i
\]
Here, $p_i$ is the additional motor movement required to get the mechanism into the requested direction and $m_i$ is the actual motor-step command. After the command has been accepted, the slack estimate is set to the edge of the band in the new direction. If the axis was already loaded in the same direction, $p_i$ is zero or small. If the direction reverses from one edge of the band to the other, $p_i$ becomes approximately the full backlash width. If raw movement is requested, for example during calibration or when joystick compensation is disabled, the motor command remains $m_i=d_i$, but the internal slack estimate is still updated and clamped inside the band.

\input{figures/fig_backlash_band}

This differs from a simple direction-sign model that was also implemented and evaluated during development. In a sign model, a static compensation amount is added only when the direction changes. The final approach tracks the slack inside a hysteresis band, illustrated in Figure~\ref{fig:backlash-band}, and therefore also handles partial movements within the band. This is more appropriate because backlash is not random measurement noise. It is deterministic, caused by the mechanical drive path. Without an independent position sensor to measure the actual stage position, the software must rely on its internal model of the slack state to plan compensation. The hysteresis-band model allows the software to maintain a more accurate estimate of the current slack state over time, which is necessary for consistent compensation.

Backlash compensation applies to automated moves and also to joystick movement. When joystick direction changes, the slack amount is taken up first as part of the motor command. This makes manual movement more consistent with the compensation state used by automation. A setting can disable joystick backlash compensation for debugging or user preference.

The backlash widths are determined during the objective-calibration workflow. The operator selects an axis, records a reference camera crop, and then jogs the axis in the opposite direction in known motor-step increments. The image-correlation measurement reports when the specimen image starts to move again after the reversal. The accumulated reverse steps can then be accepted as the backlash value for that axis and are written to the objective profiles. X and Y can be checked optically in this way because their backlash produces lateral image displacement. Z backlash is also represented by the same model, but it cannot be measured reliably with the same lateral image-correlation method and is therefore configured from the observed focus-drive behavior.

The model was evaluated as part of the motion-accuracy experiment in Section~\ref{sec:evaluation}. That experiment compares uncompensated movement, the earlier sign-based model, and the hysteresis-band model using forward displacement error and reversal residuals.

\subsection{Limits of Open-Loop Motion Control}

The platform remains open-loop. It estimates position from motor commands rather than measuring the actual sample position continuously. This limits the conclusions that can be drawn about accuracy. The software can compensate deterministic backlash according to its model, but it cannot detect all missed steps, mechanical flex, sample drift, or manual disturbance. The stage can also be moved by hand, which invalidates the backlash history and requires resetting or recalibrating the state.

The thesis therefore evaluates RetroScope as a practical low-cost retrofit, not as a closed-loop precision stage. The relevant question is whether calibration and compensation make the system usable for workflows such as focus stacking, tile scanning, and measurement within prototype constraints. For stronger accuracy claims, future versions would need encoders, optical feedback, or direct stage-position sensing.

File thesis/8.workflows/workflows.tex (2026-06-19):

\subsection{Calibrated Live View and Measurement}

The live view is the central user-facing workflow. It combines the camera preview with overlays (scale bar and grid), objective selection, focus controls, histogram display, and backlash visualization.

\begin{figure}[H]
    \centering
    
    \caption[Live-view interface]{The live-view interface: camera preview with scale bar, crosshair and grid overlays,
    objective selection, histogram, focus-quality badge, and touch controls.}
    \label{fig:ui-live}
\end{figure}

Measurement tools depend on objective calibration. The measurement view allows distances, rectangles, and angles to be placed in image coordinates and displayed in calibrated units. This requires a valid micrometers-per-pixel value for the active objective. The measurement workflow therefore demonstrates the connection between objective profiles, image calibration, live camera display, and UI interaction.

\begin{figure}[H]
    \centering
    
    \caption[Measurement interface]{The measurement interface: distance, rectangle, and angle tools that display calibrated values based on the active objective.}
    \label{fig:ui-measure}
\end{figure}

\subsection{Autofocus}

The autofocus workflow moves the Z axis through a configured search range and evaluates focus scores from the camera stream. The current position is the center of the search range, because the user usually begins near an approximate focus position. Then the workflow performs a coarse sweep up half the search range, then all the way down, followed by a fine sweep around the best coarse position. The workflow uses parabolic interpolation to refine the best position from the discrete samples. The autofocus service uses configured presets and parameters, including settle time, move-start delay, coarse and fine positions, samples per position, and minimum confidence. When minimum confidence is not met, the workflow returns to the start position.

The focus metric uses image sharpness cues derived from the luma/grayscale image. The implementation is guided by known autofocus approaches in microscopy \cite{pech2000diatom,sun2004autofocusing}, but it is adapted to the practical constraints of the camera path. The workflow validates that the camera analysis stream, Z motion, objective configuration, and UI state can work together. Figure~\ref{fig:autofocus-sweep} sketches the two-stage coarse/fine sweep and the parabolic peak refinement.

\input{figures/fig_autofocus_sweep}

\subsection{Focus Stacking}

Focus stacking captures a sequence of images at different Z positions and combines them into a result with increased apparent depth of field. In RetroScope, focus stacking uses calibrated Z motion and objective-specific step settings. It captures native-resolution frames so that all planes have consistent dimensions and sufficient detail.

The final image uses OME-TIFF. It can store both the blended result and the individual frames as separate planes with coordinates. This is important because it preserves the raw acquisition data rather than only the processed stack result. External tools can inspect the original planes if needed.

The focus-stacking workflow is a useful validation case because it stresses several platform components at once: Z movement, blocking moves, camera capture, focus-related objective settings, metadata, and gallery display.

\begin{figure}[H]
    \centering
    \begin{subfigure}[t]{0.46\linewidth}
        \vspace{0pt}
        \centering
        \begin{tabular}[t]{@{}cc@{}}
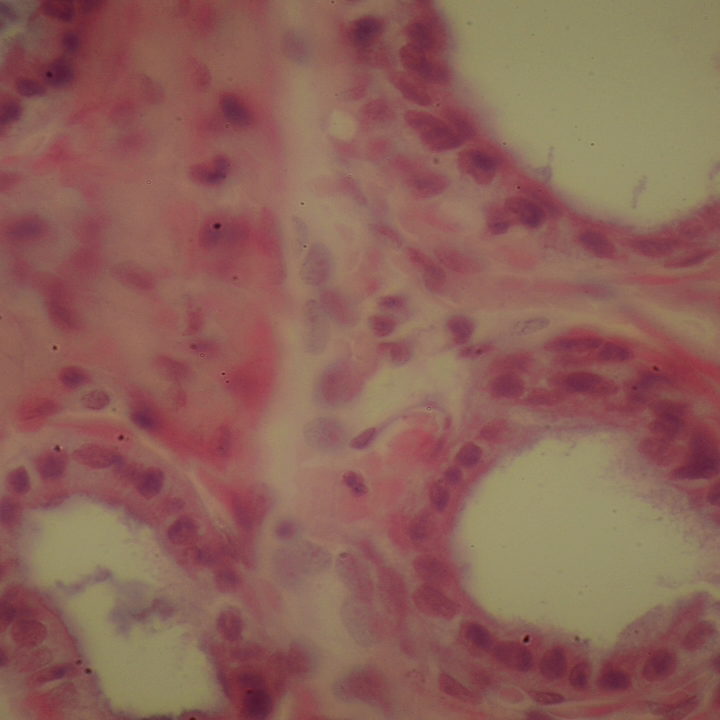
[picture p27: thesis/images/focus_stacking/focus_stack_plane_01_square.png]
             &
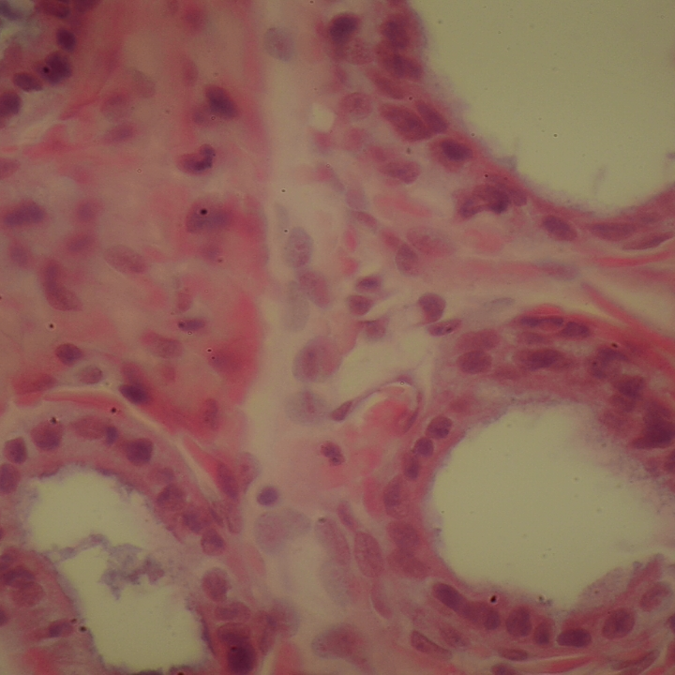
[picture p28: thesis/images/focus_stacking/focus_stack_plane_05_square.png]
             \\
            {\scriptsize Plane 1} & {\scriptsize Plane 5} \\[3pt]
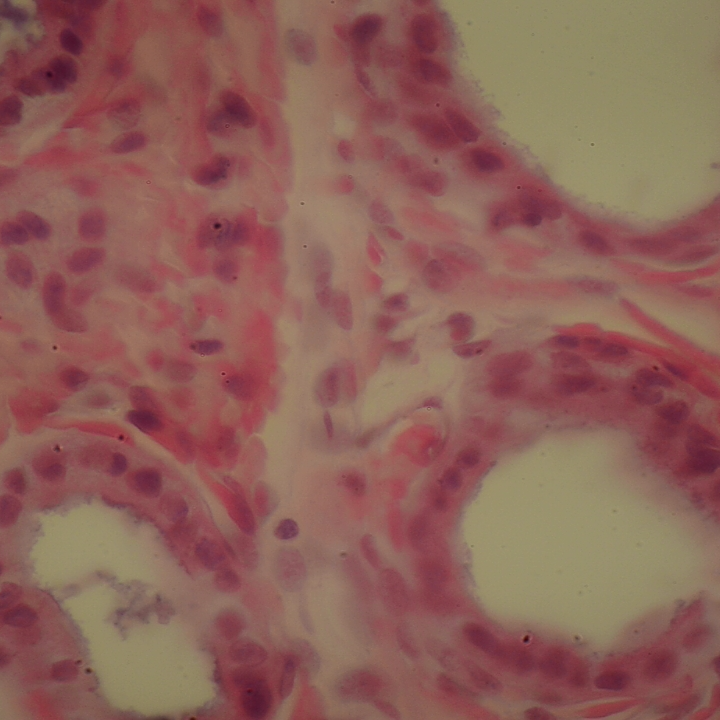
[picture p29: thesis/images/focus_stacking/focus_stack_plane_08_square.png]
             &
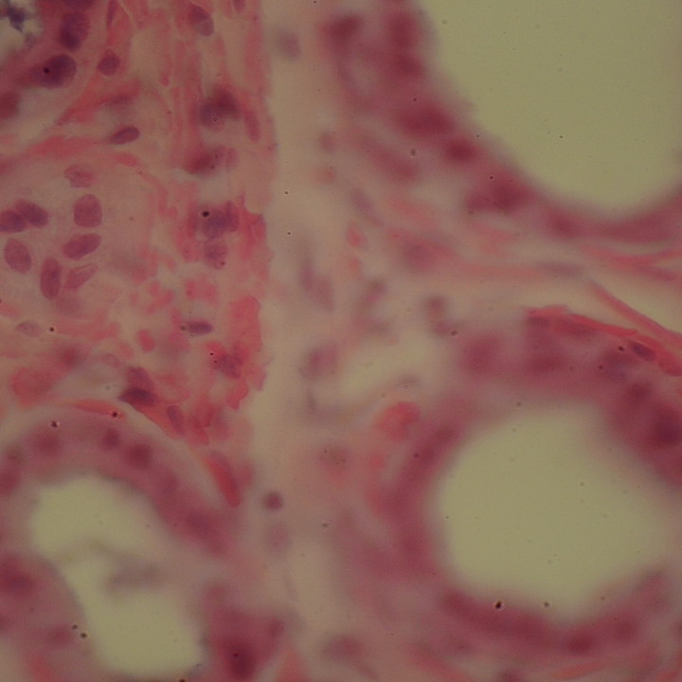
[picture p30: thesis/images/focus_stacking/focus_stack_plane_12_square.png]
             \\
            {\scriptsize Plane 8} & {\scriptsize Plane 12}
        \end{tabular}
        \caption{Selected source planes from a 12-plane focus stack example.}
    \end{subfigure}\hfill
    \begin{subfigure}[t]{0.515\linewidth}
        \vspace{0pt}
        \centering
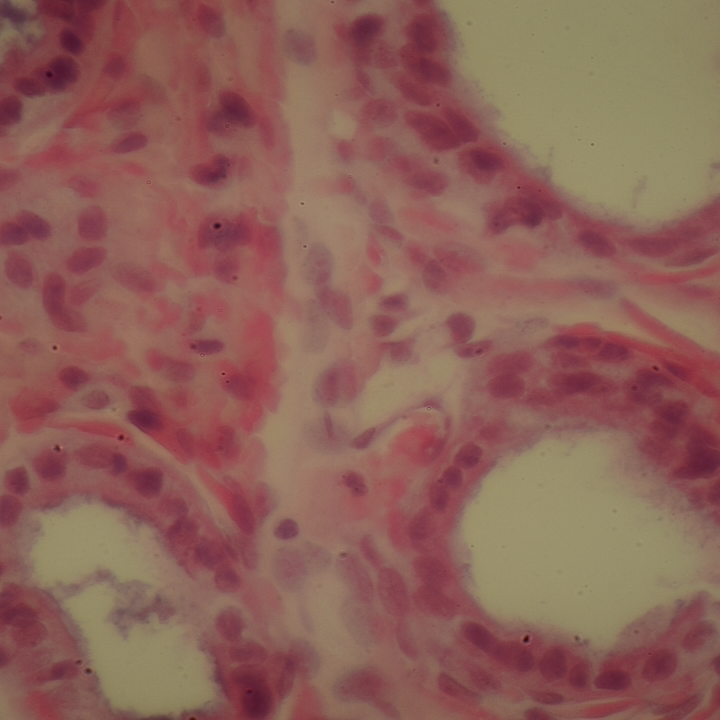
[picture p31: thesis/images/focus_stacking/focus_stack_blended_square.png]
        
        \caption{Blended all-in-focus result.}
    \end{subfigure}
    \caption[Focus-stacking example]{Example focus-stacking result: four selected Z planes (left) and the blended
    all-in-focus image (right) produced by the focus-stacking workflow.}
    \label{fig:focus-stack}
\end{figure}

\subsection{Tile Scanning and Stitching}

Tile scanning captures a grid of adjacent fields of view and stores them either as a stitched panorama or as a grid mosaic. The tile planner uses image dimensions, objective pixel scale, overlap, and calibrated stage scales to compute motor-step spacing. If stage scale is wrong, tile spacing becomes visibly wrong. If backlash is not compensated, direction changes can create irregular overlap and make stitching less reliable.

In the prototype outputs, darker tile edges and visible seams can still be seen in some stitched and mosaic results. The most likely explanation is illumination fall-off or vignetting somewhere in the camera and optical path, but the exact cause was not isolated. Other possible contributors include uneven illumination from the microscope itself, the age and condition of the 1980s optical path, or remaining calibration differences between tiles. Since each tile can be slightly darker near the frame boundary, repeated tile edges become visible when multiple tiles are placed next to one another. Reducing this artifact would require a prior flat-field correction step, where each captured tile is normalized against a reference illumination image before stitching or mosaic assembly \cite{bowman2019flatfield}.

The prototype supports different scan patterns: raster and serpentine. Raster became the default pattern because it avoids horizontal direction reversal on every row. Serpentine scanning is faster, but direction changes hurts the backlash compensation. The choice of raster scanning therefore reflects the mechanical limitations of the retrofit.

The implementation distinguishes between stitched panoramas and grid mosaics. A stitched panorama attempts image alignment and blending. A grid mosaic places full captured tiles into their grid cells while preserving overlap. The mosaic option is useful because it is deterministic and does not hide mechanical errors through image-registration behavior. The stitched option is closer to the expected user-facing result when the images contain enough texture and overlap for successful alignment. General tiled microscopy stitching is a well-established problem \cite{preibisch2009globally}.

\begin{figure}[H]
    \centering
    \begin{subfigure}[t]{0.49\linewidth}
        \centering
        
        \caption{Stitched panorama.}
    \end{subfigure}\hfill
    \begin{subfigure}[t]{0.49\linewidth}
        \centering
        
        \caption{Deterministic grid mosaic.}
    \end{subfigure}
    \caption[Tile-scan output examples]{Example tile-scan (20\% overlap) outputs from the same 3\,$\times$\,3 scan geometry: a stitched
    panorama and a grid mosaic that preserves the full tile layout and overlap.}
    \label{fig:tile-scan}
\end{figure}

\subsection{Gallery, Metadata, and Data Export}

The gallery workflow stores and displays snapshots, videos, focus stacks, and scans. It supports grid and list views, detail display, tags, metadata, thumbnails, and capture downloads through the REST API. Performance with a larger gallery was improved by generating thumbnails, instantiating only visible cells, and initializing detail content asynchronously.

Image metadata is part of the workflow. Captures include objective, position, dimensions, capture time, format, tags, and workflow-specific metadata. For images, OME-TIFF provides a metadata-rich storage format that can be opened in external microscopy tools. For external scripting, the REST API exposes capture summaries and download URLs, and the demo jupyter notebook shows a simple analysis workflow based on downloaded images.

\subsection{REST API for Remote Control and Capture Access}

RetroScope includes a FastAPI-based REST API that starts as part of the main application. It runs in a background Uvicorn thread while the Qt/QML interface remains the primary local user interface. The API is enabled by default on port 8765, provides Swagger UI at \texttt{/docs}, and exposes the OpenAPI document at \texttt{/openapi.json}. This allows a second computer on the same network to inspect the available endpoints, download captured data, or start selected actions without interacting with the touchscreen.

The current API intentionally exposes high-level application actions rather than low-level motor commands. Clients can check whether the API is alive, list gallery captures, download original capture files, trigger a still capture, and start autofocus. Capture listing supports filtering by type, sorting, limit, and offset. Downloads use an API-safe capture identifier derived from the stored capture path instead of exposing raw file paths directly.

Hardware-affecting actions are routed through the application service layer and marshalled back to the Qt thread, so remote requests use the same internal services as the local UI. The API is therefore a small remote-access surface for capture and workflow automation, not a separate motion-control
protocol. It can be extended with additional endpoints for more control and data access as needed.

\begin{table}[H]
    \centering
    \caption[REST API endpoints]{REST API endpoints for remote access and external scripting.}
    \label{tab:api}
    \begin{tabular}{@{}l l L{6.8cm}@{}}
        \toprule
        \textbf{Method} & \textbf{Endpoint} & \textbf{Purpose} \\
        \midrule
        GET  & \texttt{/api/v1/health} & API health check \\
        GET  & \texttt{/api/v1/captures} & List gallery captures with filtering, sorting, limit, and offset \\
        GET  & \texttt{/api/v1/captures/\{id\}/download} & Download an original capture \\
        POST & \texttt{/api/v1/actions/autofocus} & Start autofocus \\
        POST & \texttt{/api/v1/actions/capture} & Trigger a still capture \\
        \bottomrule
    \end{tabular}
\end{table}

The repository also contains a Jupyter notebook that demonstrates connecting to the API, listing captures, selecting a snapshot, downloading the original image, decoding it, and processing it with OpenCV. This notebook illustrates how RetroScope can act both as a local capturing interface and as a network-accessible data source for external analysis.

\begin{figure}[H]
    \centering
    \begin{subfigure}[t]{0.48\linewidth}
        \centering
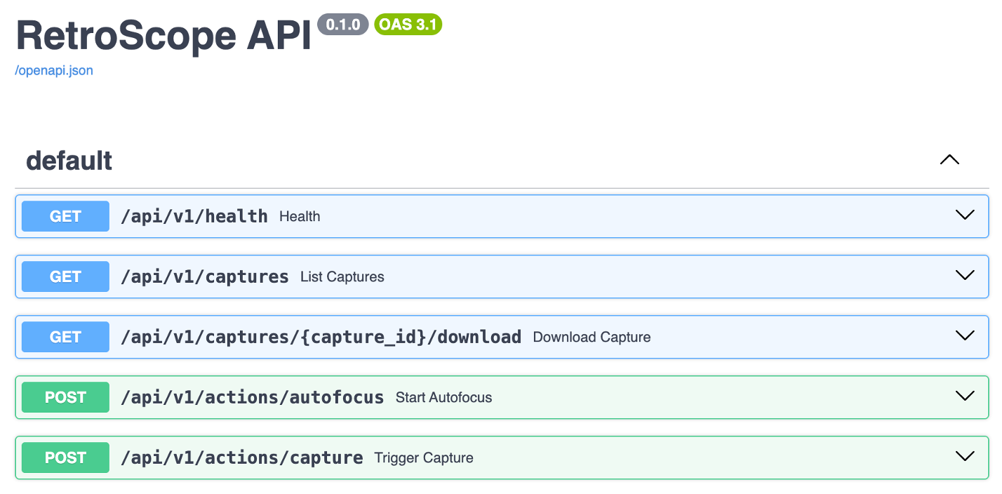
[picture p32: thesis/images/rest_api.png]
        
        \caption{Swagger UI for the REST API.}
    \end{subfigure}\hfill
    \begin{subfigure}[t]{0.48\linewidth}
        \centering
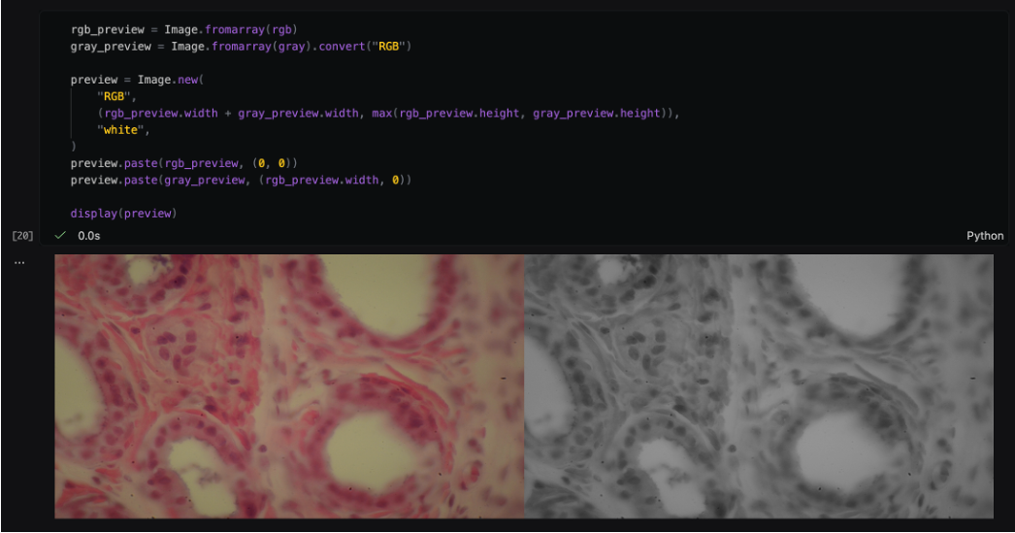
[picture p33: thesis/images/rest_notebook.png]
        
        \caption{Jupyter notebook demonstrating API usage.}
    \end{subfigure}
    \caption[REST API and notebook screenshots]{Screenshots of the Swagger UI for the REST API and Jupyter notebook demonstrating API usage.}
    \label{fig:rest}
\end{figure}

\subsection{Role of the Workflows in Validating the Platform}

The workflows are not presented as independent research contributions. Autofocus, focus stacking, tile scanning, gallery management, and measurement are standards of digital microscopy functionality. Their role in this thesis is to validate the retrofit concept. Each workflow requires a different combination of mechanics, electronics, camera handling, calibration, and motion control.

If the platform can support these workflows with low-cost hardware and parametric mechanical adapters, then the core claim of the thesis is strengthened. Conversely, workflow failures identify where the retrofit approach reaches its limits. For example, tile scanning reveals stage-scale and backlash problems, autofocus reveals focus-score and frame-analysis timing problems, gallery performance reveals memory limitations on the Raspberry Pi, and video capture reveals bandwidth and pixel-format constraints.

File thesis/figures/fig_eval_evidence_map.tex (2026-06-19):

\begin{figure}[H]
    \centering
    \begin{tikzpicture}[
        font=\small,
        box/.style={draw, rounded corners, align=center, text width=0.29\linewidth, minimum height=1.1cm, fill=gray!8},
        data/.style={draw, rounded corners, align=center, text width=0.24\linewidth, minimum height=0.9cm, fill=blue!7},
        >=Latex,
        node distance=7mm and 8mm,
    ]
        \node[box] (rq1) {RQ1\\Parametric retrofit adaptability};
        \node[box, right=of rq1] (rq2) {RQ2\\Low-cost motion and positioning};
        \node[box, right=of rq2] (rq3) {RQ3\\Calibration-enabled workflows};
        \node[data, below=of rq1] (cad) {CAD parameter variants\\Mechanical artifact};
        \node[data, below=of rq2] (motion) {Stage scale\\Motion accuracy\\Calibration repeat};
        \node[data, below=of rq3] (workflow) {Autofocus\\Focus stacking\\Tile scanning};
        \draw[-{Latex}] (cad) -- (rq1);
        \draw[-{Latex}] (motion) -- (rq2);
        \draw[-{Latex}] (motion) -- (rq3);
        \draw[-{Latex}] (workflow) -- (rq3);
    \end{tikzpicture}
    \caption[Evaluation evidence map]{Evaluation evidence map. The physical measurements mainly support RQ2 and RQ3, while RQ1 is supported by the mechanical artifact and virtual parametric adaptation rather than by a second physical microscope build.}
    \label{fig:eval-evidence-map}
\end{figure}

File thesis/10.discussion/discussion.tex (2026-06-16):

\subsection{Answering the Research Questions}

RQ1 asked whether a retrofit platform can add motorized control and digital imaging to vintage microscopes while remaining adaptable to different mechanical designs through parametric modelling. The prototype shows that this is feasible at the level of a working artifact. It adds motorized XY and Z movement, digital camera preview, calibration workflows, and automated capture workflows to the Nikon Optiphot 66 used during development. Adaptability is supported by the parametric Fusion model and by a mechanical strategy based on common microscope control interfaces, and it is demonstrated virtually. Editing the model parameters regenerates the adapter geometry for different body dimensions. Because only one suitable vintage instrument was available, this evidence is design-level rather than physical. The answer is therefore positive as a design principle, demonstrated virtually through parametric variation, while a broad empirical claim would still require adapting and building the platform on additional physical microscope bodies.

RQ2 asked whether a low-cost prototype can provide sufficiently consistent scale, motion, and positioning behavior for automated microscopy. The prototype demonstrates that low-cost open-loop hardware can be made usable, but only when its limitations are treated as part of the system design. The implemented system provides calibrated stage scales, separate X/Y/Z backlash values, soft limits, blocking movement for capture workflows, and a per-axis slack model for backlash behavior. The evaluation confirms that 4x stage-scale measurements are repeatable, especially for 200-step moves, and that hysteresis compensation substantially improves the X axis in the 200-step condition. However, without closed-loop position feedback, the system tracks commanded position rather than measured stage position. The evidence therefore supports practical consistency for prototype workflows, while precision claims must remain bounded by the measured variability and by the open-loop nature of the hardware.

RQ3 asked to what extent image-based calibration can enable automated workflows such as autofocus, focus stacking, and tile scanning. The implemented calibration system provides objective profiles, pixel scale, stage scale, backlash values, and derived scaling across objectives. These calibrated quantities allow the software to translate image observations and workflow settings into motor commands, overlap planning, focus ranges, and measurement units. In the workflow evaluation, autofocus, focus stacking, and tile scanning each completed 10/10 runs for the 4x, 20x, 40x, and 63x profiles. The answer is that image-based calibration is a necessary layer for these workflows, but reliability also depends on motion compensation, blocking logic, and careful performance management.

\subsection{Trade-Offs of the Retrofit Approach}

The main advantage of retrofitting is reuse. A vintage microscope can gain digital imaging and automation without replacing the optical instrument. The platform can remain affordable, inspectable, and adaptable. It can also be built around open-source artifacts, which supports modification and learning.

The main disadvantage is inherited uncertainty. The retrofit must work through existing controls, printed adapters, and low-cost motors. The software does not control a precision stage directly. It controls a chain of mechanics that includes slack, friction, flex, and calibration uncertainty. This makes the system more sensitive to physical assembly and calibration than an integrated commercial platform.

This trade-off is acceptable for the stated goal of the thesis. RetroScope is not presented as a replacement for high-end motorized microscopes. It is presented as an open platform that extends older microscopes lifetime with useful digital and automated capabilities.

\subsection{Low-Cost Hardware Versus Precision}

Low-cost hardware expands accessibility but reduces precision margins. The 28BYJ motors, printed gears, and open-loop control are affordable and easy to reproduce, but they create backlash and motion variability. The Raspberry Pi provides enough computation for the application, but performance-sensitive paths such as frame analysis and gallery rendering had to be optimized.

The prototype shows that these limitations can be managed, but not ignored. The final system separates live preview from frame analysis, uses native capture for high-resolution imaging, adds blocking moves for capture workflows, and tracks backlash slack. These changes are all consequences of using constrained hardware.

\subsection{Software Compensation Versus Mechanical Limits}

Software compensation is powerful when the mechanical error is predictable. Backlash is partly predictable because direction changes consume slack before physical movement occurs. The hysteresis-band model captures this deterministic behavior better than treating backlash as random noise. Similarly, stage-scale calibration can correct systematic differences between X and Y movement.

Software compensation is less effective when the mechanical state changes unpredictably. Printed parts can flex, screws can loosen, the stage can be moved by hand, friction can change after lubrication, and a motor can miss steps. Without direct feedback, the software cannot observe all of these events. This is why the platform invalidates backlash history after certain events and why calibration remains central.

The practical lesson is that mechanical and software design must be co-developed. The adapter should reduce backlash and flex as much as possible, while the software compensates what remains. Neither side is sufficient alone.

\subsection{Limitations}

The main limitation is that the prototype has been built and evaluated on a single physical microscope body, the Nikon Optiphot 66, because no second suitable vintage instrument was available and a second physical build was out of scope. This limits empirical claims about general mechanical adaptability. The parametric model supports adaptation and this is demonstrated virtually through parameter variation, but a stronger evaluation would build the platform on additional physical microscopes with different focus and stage geometries.

A second limitation is the lack of closed-loop position feedback. The platform tracks commanded motor position, not measured sample position. This affects motion accuracy, backlash compensation, and repeatability. The system can be useful without encoders, but accuracy claims must remain bounded by the open-loop nature of the design.

A third limitation is the scope of the quantitative evaluation data. The current datasets cover 4x stage-scale, 4x motion behavior, 4x calibration repeatability, and workflow reliability for 4x, 20x, 40x, and 63x. They do not include other objective profiles, closed-loop position measurements, or physical validation on a second microscope body.

Finally, the thesis is partly based on a evolving software artifact. This creates a risk that described behavior may drift from the final repository state. The evaluation was run on a specific commit: 13ada32.

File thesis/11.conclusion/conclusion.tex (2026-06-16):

\subsection{Summary}

This thesis presented RetroScope, an open retrofit platform for motorizing and digitizing vintage microscopes. The work started from the observation that many microscopes share user-facing control interfaces such as focus knobs, and XY-stage knobs. RetroScope uses these interfaces instead of replacing the microscope's internal mechanics. A parametric mechanical adapter, low-cost embedded electronics, modular software stack, and image-based calibration process are combined into a working prototype.

The prototype demonstrates motorized XY and Z control, live digital imaging, objective profiles, calibrated measurement, autofocus, focus stacking, tile scanning, and REST-based remote access. The workflows are enabled by calibration and motion compensation rather than by high-end mechanical hardware. This is the central result of the thesis: a low-cost retrofit can become useful when mechanical adaptation, embedded control, software architecture, and calibration are designed together.

\subsection{Future Work}

Future work should begin with extending the quantitative validation. The current evaluation already covers 4x stage scale, 4x motion accuracy, 4x calibration repeatability, and workflow reliability across several objective profiles. The next step is to add higher-magnification calibration, motion, and stage-scale datasets, objective quality metrics for focus stacks and tile scans, and a comparison of alternative higher-performance, higher-cost component choices. The parametric adapter's adaptability is demonstrated virtually in this thesis through parameter variation on the Nikon Optiphot 66 model. Building the platform on additional physical microscope bodies would turn this into empirical evidence and further strengthen the adaptability claim.

The mechanical design could be improved through stiffer materials, metal inserts or machined parts in high-load areas, and better gear support. The motion system could be improved through closed-loop feedback, for example with motor encoders, stage encoders, optical tracking, or other position sensors.

The software could be extended with richer REST endpoints, remote live-view streaming, additional capture formats, and more robust stitching.

RetroScope therefore remains both a working prototype and a platform for further development. Its main value is not that it removes all limitations of low-cost retrofit hardware, but that it shows a coherent path for giving vintage microscopes a longer lifetime with programmable and digital capabilities.

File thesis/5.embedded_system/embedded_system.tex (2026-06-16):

\subsection{Overall System Architecture}

The embedded system architecture connects the microscope, mechanical adapters, electronics, camera input, touchscreen, and software into one control platform. The Raspberry Pi acts as the central computer. It runs the Python/PySide application, renders the QML interface, receives camera frames, communicates with the motor controller, reads user input devices, stores captures, and exposes the REST API. The motor controller drives the stepper motors for the XY stage and focus axis. Additional devices provide joystick input, focus encoder input, buttons, endstop, and optional current sensing.

The system is intentionally modular. Hardware-specific behavior is isolated in drivers, application behavior is implemented in services, pure calculations are placed in domain modules, bridge classes expose state and commands to QML, and the QML files implement the touch interface. This separation makes the system easier to test and modify. It also supports mock mode, where parts of the system can run without the physical microscope.

\subsection{Hardware Selection and Cost Constraints}

The prototype hardware was selected under low-cost and reproducibility constraints. The selected components include a Raspberry Pi 4, DSI touchscreen, Elgato Cam Link, Sangaboard, 28BYJ-48 stepper motors, analog joystick, ADS1115 analog-to-digital converter, incremental rotary encoder, endstop, and buttons.

The Sangaboard was selected as the dedicated motor-controller board. In this thesis, Sangaboard is an open-source motor controller placed between the Raspberry Pi and the stepper motors: it receives serial commands from the host over UART, drives the motor coils, and reports motor step counts back to the application. It is part of the OpenFlexure ecosystem \cite{collins2020openflexure,openflexureDocs}. RetroScope reuses this motor controller for a different purpose: instead of driving a printed OpenFlexure microscope stage, the Sangaboard drives retrofit adapters attached to the existing XY stage and fine-focus mechanism.

The 28BYJ-48 motors were chosen because they are inexpensive and easy to drive. A direct-drive stepper alternative was considered. It would offer easier manual rotation and different mechanical behavior, but it would require a higher-voltage, higher-current supply, a different motor controller, and protection against generated electrical energy when rotated manually. The chosen hardware therefore reflects the thesis goal: explore how far a low-cost retrofit can be pushed rather than eliminating all limitations through more expensive components.

Table~\ref{tab:components} lists the main electronic and mechanical components and their role in the
platform. The priced bill of materials with suppliers and total prototype cost is given in
Appendix~\ref{app:bom}. Exact prices depend on supplier and date.

\begin{table}[H]
    \centering
    \caption[Main hardware components]{Main hardware components of the RetroScope prototype and their role.}
    \label{tab:components}
    \begin{tabular}{@{}L{4.8cm} c L{6.8cm}@{}}
        \toprule
        \textbf{Component} & \textbf{Qty} & \textbf{Role / interface} \\
        \midrule
        Raspberry Pi 4 Model B (4\,GB) & 1 & Central computer, runs the PySide6/QML application and REST API \\
        DSI capacitive touchscreen & 1 & Primary touch user interface \\
        Elgato Cam Link & 1 & UVC video capture of the microscope camera (USB) \\
        Sangaboard motor controller & 1 & Stepper driving and step counting (UART) \\
        28BYJ-48 geared stepper motor & 3 & X-stage, Y-stage, and focus drives \\
        Analog joystick ($2\times10\,\mathrm{k}\Omega$) & 1 & Manual XY motion \\
        ADS1115 ADC module & 1 & Joystick analog-to-digital conversion (I\textsuperscript{2}C) \\
        Incremental rotary encoder & 1 & Manual focus (Z) input \\
        INA219 current-sense module & 2 & Motor current / stall sensing, not used for final control logic (I\textsuperscript{2}C) \\
        Logic-level shifter (BSS138) & 1 & 5\,V\ to 3.3\,V protection for GPIO inputs \\
        Endstop switch & 1 & Focus-axis (Z) safety limit \\
        Push button & 4 & Assignable user actions \\
        Custom PCB & 1 & Consolidates wiring, components, level shifting, and connectors \\
        3D-printed parts (PETG, ABS-GF) & -- & Adapters, motor mounts, brackets, enclosure, ... \\
        \bottomrule
    \end{tabular}
\end{table}

\subsection{Raspberry Pi, Display, Camera, and Video Capture}

The Raspberry Pi provides the computational and interface core of the platform. It runs the QML touchscreen interface and the Python backend, and it connects to the display, camera capture device, motor controller, and peripheral electronics.

Camera input was one of the more difficult implementation areas. The Cam Link appeared as a standard UVC device on Linux. A 4K signal produced too much USB bandwidth for the Raspberry Pi 4, requiring downscaling to 1080p and the camera formats NV12 and YU12 required color conversion. The camera system was structured into multiple paths: a direct preview path for low-latency QML video output, a CPU frame-analysis path at configurable resolution and frame rate, a native still-capture path for full-resolution snapshots and automated captures, and a native recording path for video.

Live preview is seperated from frame analysis. Live video can remain responsive while the analysis path computes histogram values, focus scores, and objective-change metrics at a lower rate. This separation was important because frame analysis originally affected the performance of the live preview and responsiveness of e.g. the joystick.

\subsection{Motor Controller, Stepper Motors, and Input Devices}

The Sangaboard communicates with the Raspberry Pi over UART and controls the stepper motors. Disabling Bluetooth on the Raspberry Pi was necessary to use the full PL011 UART for Sangaboard communication because the mini UART has a smaller FIFO size.

Manual input is provided through a joystick for XY movement and a rotary encoder for focus movement. The joystick uses two potentiometer axes connected through an ADS1115 ADC over I\textsuperscript{2}C. The rotary encoder is used for Z control. A logic-level shifter was necessary because the encoder operates at 5 V while Raspberry Pi GPIO pins are 3.3 V tolerant. The system also includes buttons for user actions such as autofocus or recording, and an endstop to prevent dangerous focus movement, like crashing the objective into the sample.

\subsection{Custom PCB, Wiring, and Power Distribution}

The custom PCB replaces breadboard wiring and makes the prototype more reproducible. The KiCad project in the repository contains schematic, PCB, symbol, Gerber, drill, and STEP files. The schematic and board files show connectors for the Raspberry Pi, joystick/ADC path, INA219 modules, level shifting, endstop/buttons, and power rails. The board uses 5 V and 3.3 V rails and common ground, with I\textsuperscript{2}C shared by several modules.

The two INA219 current-sense modules are included in the final PCB and wiring, but they are not used by the final prototype for motor stall detection. They were originally added to detect abnormal motor load through supply-current changes. In practice, this was not reliable with the unipolar 28BYJ-48 motors and the Sangaboard drive pattern: depending on the current step phase, one or two coils can be energised, so the measured current is dominated by the coil-energising sequence rather than by a clearly readable load or stall signal. The modules are therefore still shown in the hardware list, bill of materials, schematic, and wiring table because they are physically part of the built PCB, but the software does not depend on them for the final motion-control behaviour.

\begin{figure}[H]
    \centering
    \begin{subfigure}[t]{0.48\linewidth}
        \centering
        
        \caption{Assembled board.}
    \end{subfigure}\hfill
    \begin{subfigure}[t]{0.48\linewidth}
        \centering
        
        \caption{PCB routing with modules, connectors, and power rails.}
    \end{subfigure}
    \caption[Assembled custom PCB]{The assembled RetroScope custom PCB (KiCad design, manufactured via JLCPCB),
    consolidating the joystick ADC, current-sense modules, level shifting, endstop/button
    connectors, and power rails. The board files are listed in Appendix~\ref{app:pcb}.}
    \label{fig:pcb}
\end{figure}

Table~\ref{tab:wiring} summarises the signal routing: the Sangaboard UART,
the level-shifted encoder inputs, the endstop and buttons, the shared I\textsuperscript{2}C bus with
its device addresses, and the power rails. The full pin map and the KiCad/Gerber references are
reproduced in Appendix~\ref{app:wiring} and Appendix~\ref{app:pcb}.
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

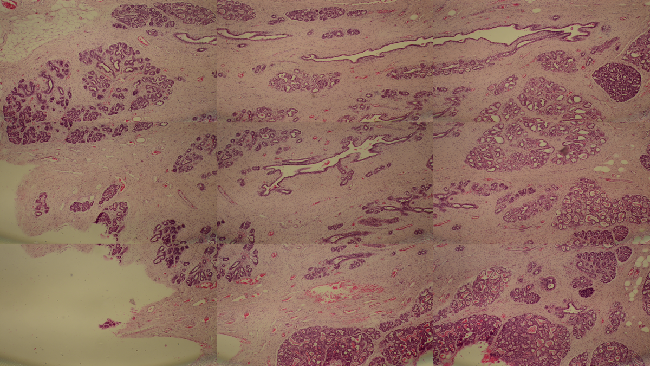
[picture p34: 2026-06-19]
paper/figures/tile_scan_mosaic.png

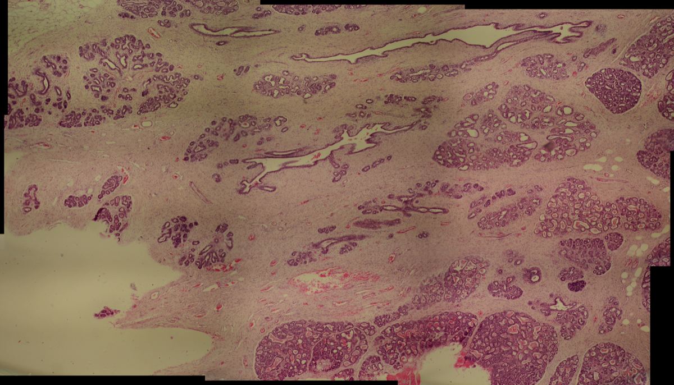
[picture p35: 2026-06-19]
paper/figures/tile_scan_stitched.png

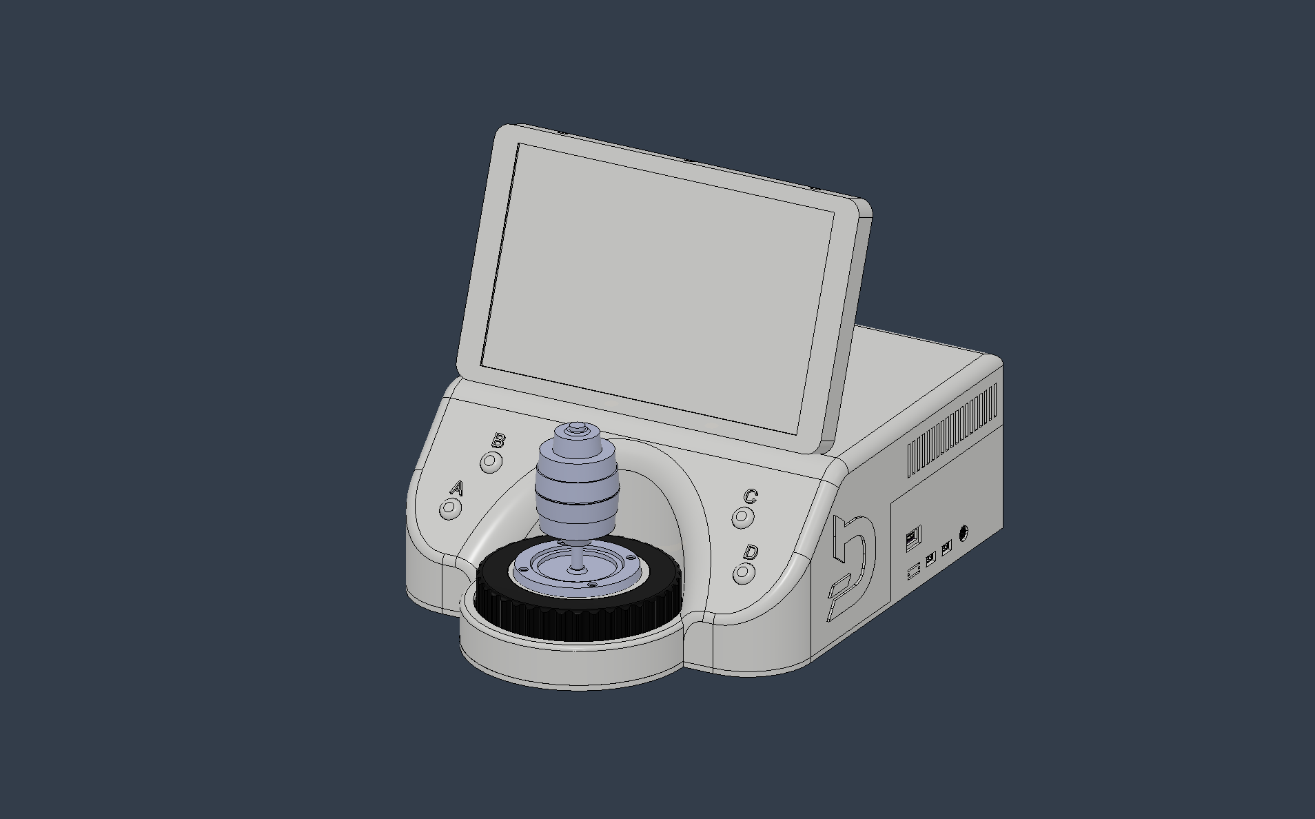
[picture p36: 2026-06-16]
thesis/images/adapter/body_only.png

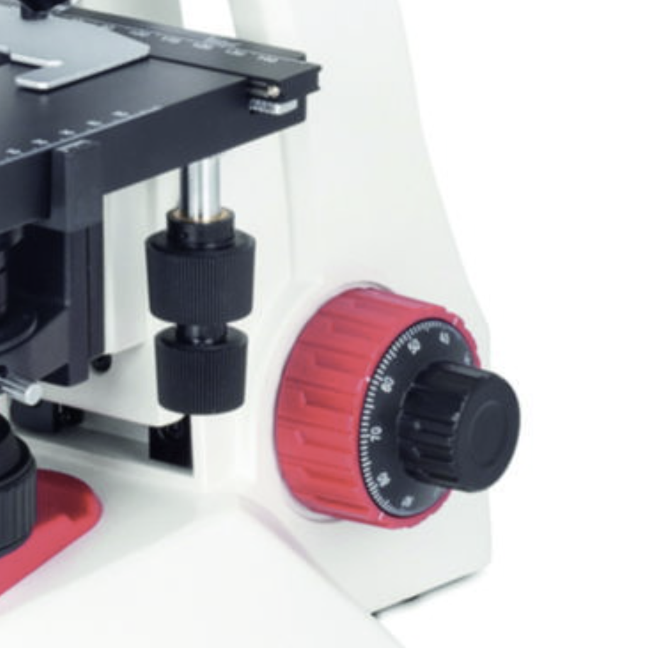
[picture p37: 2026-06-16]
thesis/images/shared_interface/MOTIC RED 233.png

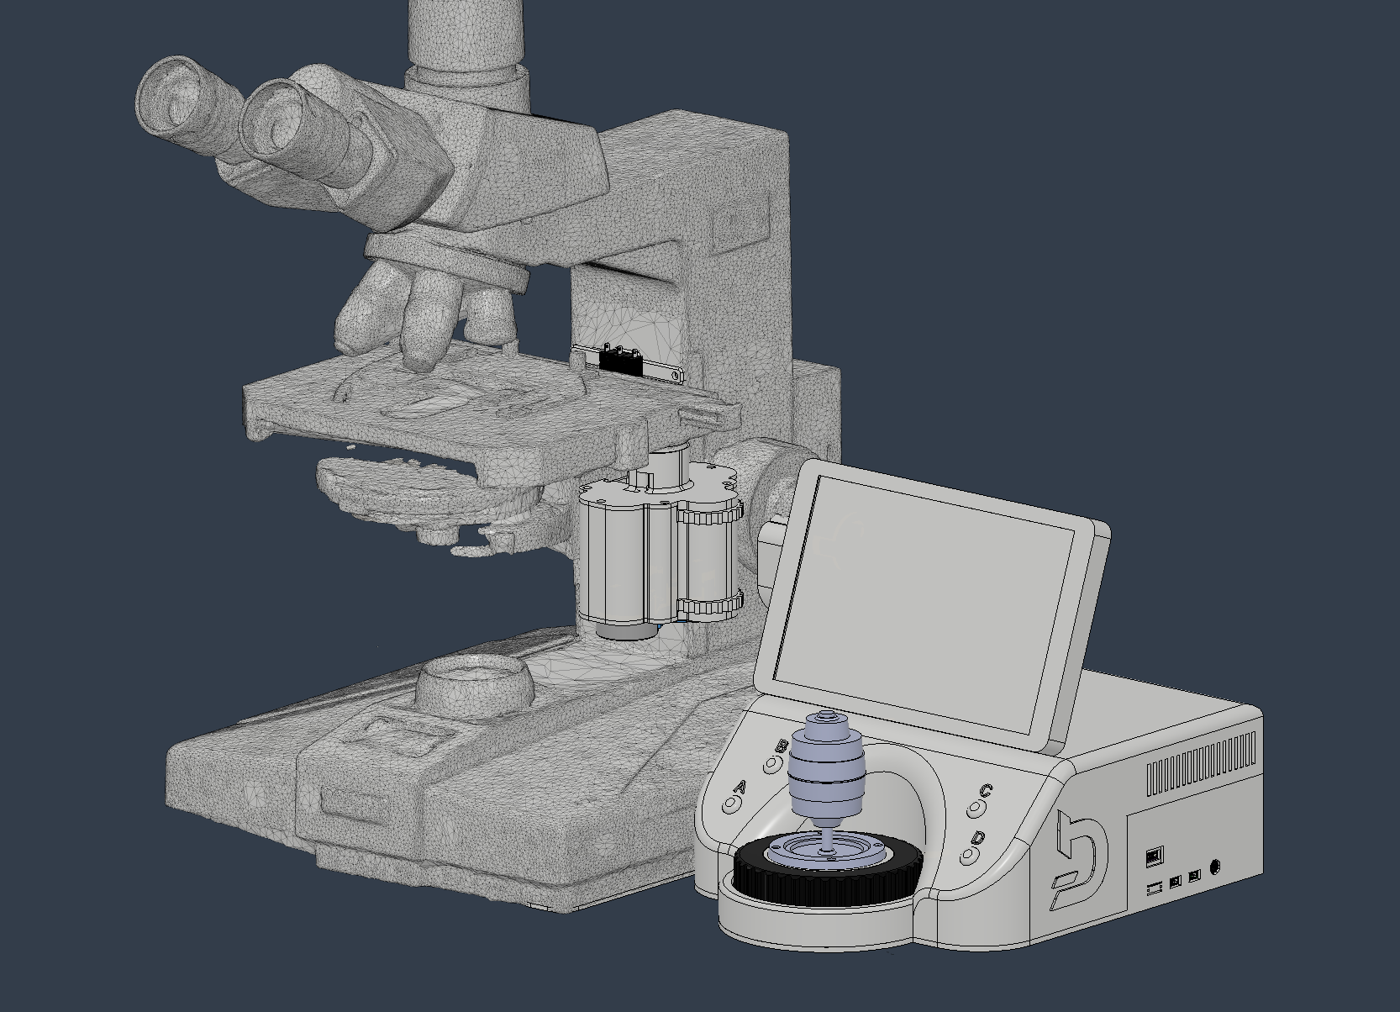
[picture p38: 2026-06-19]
thesis/images/with_scan.png

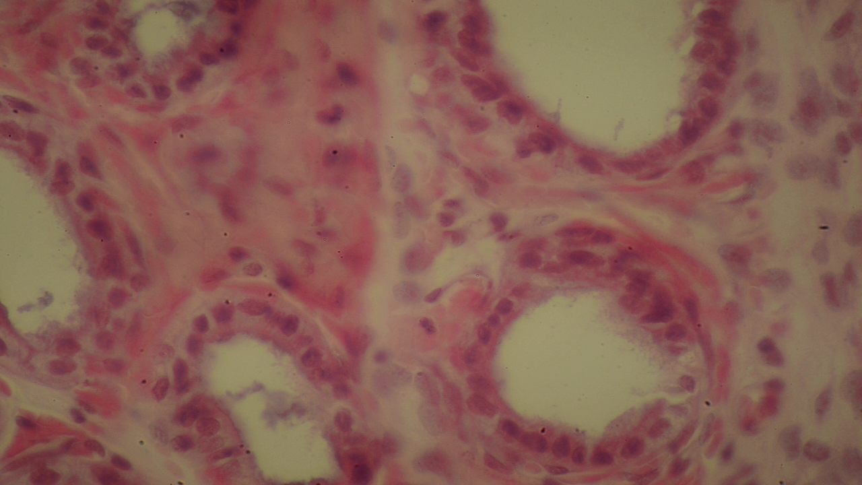
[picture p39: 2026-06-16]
thesis/images/focus_stacking/focus_stack_plane_01.png

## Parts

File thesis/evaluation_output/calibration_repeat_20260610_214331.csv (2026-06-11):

row_type | objective_slot | objective_name | objective_display_name | objective_numerical_aperture | objective_um_per_pixel | objective_backlash_x | objective_backlash_y | objective_backlash_z | objective_dof_steps | objective_focus_stack_step | objective_autofocus_range_steps | stage_um_per_step_x | stage_um_per_step_y | quantity | rep | valid | reason | value | phase_response | template_score
trial | 4x | 4x | 4x | 0.1 | 3.672704687965688 | 100 | 130 | 20 | 803 | 402 | 8030 | 2.2647613696231015 | 3.2719607095945618 | stage_scale_X_um_per_step | 0 | True |  | 2.18379
trial | 4x | 4x | 4x | 0.1 | 3.672704687965688 | 100 | 130 | 20 | 803 | 402 | 8030 | 2.2647613696231015 | 3.2719607095945618 | stage_scale_X_um_per_step | 1 | True |  | 2.12677
trial | 4x | 4x | 4x | 0.1 | 3.672704687965688 | 100 | 130 | 20 | 803 | 402 | 8030 | 2.2647613696231015 | 3.2719607095945618 | stage_scale_X_um_per_step | 2 | True |  | 2.29834
trial | 4x | 4x | 4x | 0.1 | 3.672704687965688 | 100 | 130 | 20 | 803 | 402 | 8030 | 2.2647613696231015 | 3.2719607095945618 | stage_scale_X_um_per_step | 3 | True |  | 2.29945
trial | 4x | 4x | 4x | 0.1 | 3.672704687965688 | 100 | 130 | 20 | 803 | 402 | 8030 | 2.2647613696231015 | 3.2719607095945618 | stage_scale_X_um_per_step | 4 | True |  | 2.32028
trial | 4x | 4x | 4x | 0.1 | 3.672704687965688 | 100 | 130 | 20 | 803 | 402 | 8030 | 2.2647613696231015 | 3.2719607095945618 | stage_scale_X_um_per_step | 5 | True |  | 2.13478
trial | 4x | 4x | 4x | 0.1 | 3.672704687965688 | 100 | 130 | 20 | 803 | 402 | 8030 | 2.2647613696231015 | 3.2719607095945618 | stage_scale_X_um_per_step | 6 | True |  | 2.14105
trial | 4x | 4x | 4x | 0.1 | 3.672704687965688 | 100 | 130 | 20 | 803 | 402 | 8030 | 2.2647613696231015 | 3.2719607095945618 | stage_scale_X_um_per_step | 7 | True |  | 2.26987
trial | 4x | 4x | 4x | 0.1 | 3.672704687965688 | 100 | 130 | 20 | 803 | 402 | 8030 | 2.2647613696231015 | 3.2719607095945618 | stage_scale_X_um_per_step | 8 | True |  | 2.27267
trial | 4x | 4x | 4x | 0.1 | 3.672704687965688 | 100 | 130 | 20 | 803 | 402 | 8030 | 2.2647613696231015 | 3.2719607095945618 | stage_scale_X_um_per_step | 9 | True |  | 2.26645
trial | 4x | 4x | 4x | 0.1 | 3.672704687965688 | 100 | 130 | 20 | 803 | 402 | 8030 | 2.2647613696231015 | 3.2719607095945618 | stage_scale_X_um_per_step | 10 | True |  | 2.20686
trial | 4x | 4x | 4x | 0.1 | 3.672704687965688 | 100 | 130 | 20 | 803 | 402 | 8030 | 2.2647613696231015 | 3.2719607095945618 | stage_scale_X_um_per_step | 11 | True |  | 2.26282
trial | 10x | 10x | 20x | 0.25 | 0.7345409375931375 | 100 | 130 | 20 | 128 | 64 | 1280 | 2.2647613696231015 | 3.2719607095945618 | stage_scale_X_um_per_step | 0 | True |  | 0.01204
trial | 10x | 10x | 20x | 0.25 | 0.7345409375931375 | 100 | 130 | 20 | 128 | 64 | 1280 | 2.2647613696231015 | 3.2719607095945618 | stage_scale_X_um_per_step | 1 | True |  | 2.24438
trial | 10x | 10x | 20x | 0.25 | 0.7345409375931375 | 100 | 130 | 20 | 128 | 64 | 1280 | 2.2647613696231015 | 3.2719607095945618 | stage_scale_X_um_per_step | 2 | True |  | 2.22338
trial | 10x | 10x | 20x | 0.25 | 0.7345409375931375 | 100 | 130 | 20 | 128 | 64 | 1280 | 2.2647613696231015 | 3.2719607095945618 | stage_scale_X_um_per_step | 3 | True |  | 2.44222
trial | 10x | 10x | 20x | 0.25 | 0.7345409375931375 | 100 | 130 | 20 | 128 | 64 | 1280 | 2.2647613696231015 | 3.2719607095945618 | stage_scale_X_um_per_step | 4 | True |  | 2.12604
trial | 10x | 10x | 20x | 0.25 | 0.7345409375931375 | 100 | 130 | 20 | 128 | 64 | 1280 | 2.2647613696231015 | 3.2719607095945618 | stage_scale_X_um_per_step | 5 | True |  | 2.13004
trial | 10x | 10x | 20x | 0.25 | 0.7345409375931375 | 100 | 130 | 20 | 128 | 64 | 1280 | 2.2647613696231015 | 3.2719607095945618 | stage_scale_X_um_per_step | 6 | True |  | 2.293
trial | 10x | 10x | 20x | 0.25 | 0.7345409375931375 | 100 | 130 | 20 | 128 | 64 | 1280 | 2.2647613696231015 | 3.2719607095945618 | stage_scale_X_um_per_step | 7 | True |  | 2.32314
trial | 10x | 10x | 20x | 0.25 | 0.7345409375931375 | 100 | 130 | 20 | 128 | 64 | 1280 | 2.2647613696231015 | 3.2719607095945618 | stage_scale_X_um_per_step | 8 | True |  | 2.32314
trial | 10x | 10x | 20x | 0.25 | 0.7345409375931375 | 100 | 130 | 20 | 128 | 64 | 1280 | 2.2647613696231015 | 3.2719607095945618 | stage_scale_X_um_per_step | 9 | True |  | 2.23234
trial | 10x | 10x | 20x | 0.25 | 0.7345409375931375 | 100 | 130 | 20 | 128 | 64 | 1280 | 2.2647613696231015 | 3.2719607095945618 | stage_scale_X_um_per_step | 10 | True |  | 2.14534
trial | 4x | 4x | 4x | 0.1 | 3.672704687965688 | 100 | 130 | 20 | 803 | 402 | 8030 | 2.2647613696231015 | 3.2719607095945618 | stage_scale_Y_um_per_step | 0 | True |  | 3.38931
trial | 4x | 4x | 4x | 0.1 | 3.672704687965688 | 100 | 130 | 20 | 803 | 402 | 8030 | 2.2647613696231015 | 3.2719607095945618 | stage_scale_Y_um_per_step | 1 | True |  | 3.16775
trial | 4x | 4x | 4x | 0.1 | 3.672704687965688 | 100 | 130 | 20 | 803 | 402 | 8030 | 2.2647613696231015 | 3.2719607095945618 | stage_scale_Y_um_per_step | 2 | True |  | 3.15994
trial | 4x | 4x | 4x | 0.1 | 3.672704687965688 | 100 | 130 | 20 | 803 | 402 | 8030 | 2.2647613696231015 | 3.2719607095945618 | stage_scale_Y_um_per_step | 3 | True |  | 3.17463
trial | 4x | 4x | 4x | 0.1 | 3.672704687965688 | 100 | 130 | 20 | 803 | 402 | 8030 | 2.2647613696231015 | 3.2719607095945618 | stage_scale_Y_um_per_step | 4 | True |  | 3.00738
trial | 4x | 4x | 4x | 0.1 | 3.672704687965688 | 100 | 130 | 20 | 803 | 402 | 8030 | 2.2647613696231015 | 3.2719607095945618 | stage_scale_Y_um_per_step | 5 | True |  | 3.00095
trial | 4x | 4x | 4x | 0.1 | 3.672704687965688 | 100 | 130 | 20 | 803 | 402 | 8030 | 2.2647613696231015 | 3.2719607095945618 | stage_scale_Y_um_per_step | 6 | True |  | 3.07761
trial | 4x | 4x | 4x | 0.1 | 3.672704687965688 | 100 | 130 | 20 | 803 | 402 | 8030 | 2.2647613696231015 | 3.2719607095945618 | stage_scale_Y_um_per_step | 7 | True |  | 3.18455
trial | 4x | 4x | 4x | 0.1 | 3.672704687965688 | 100 | 130 | 20 | 803 | 402 | 8030 | 2.2647613696231015 | 3.2719607095945618 | stage_scale_Y_um_per_step | 8 | True |  | 3.18131
trial | 4x | 4x | 4x | 0.1 | 3.672704687965688 | 100 | 130 | 20 | 803 | 402 | 8030 | 2.2647613696231015 | 3.2719607095945618 | stage_scale_Y_um_per_step | 9 | True |  | 3.13163
trial | 10x | 10x | 20x | 0.25 | 0.7345409375931375 | 100 | 130 | 20 | 128 | 64 | 1280 | 2.2647613696231015 | 3.2719607095945618 | stage_scale_Y_um_per_step | 0 | True |  | 3.0214
trial | 10x | 10x | 20x | 0.25 | 0.7345409375931375 | 100 | 130 | 20 | 128 | 64 | 1280 | 2.2647613696231015 | 3.2719607095945618 | stage_scale_Y_um_per_step | 1 | True |  | 0.01357
trial | 10x | 10x | 20x | 0.25 | 0.7345409375931375 | 100 | 130 | 20 | 128 | 64 | 1280 | 2.2647613696231015 | 3.2719607095945618 | stage_scale_Y_um_per_step | 2 | True |  | 3.19132
trial | 10x | 10x | 20x | 0.25 | 0.7345409375931375 | 100 | 130 | 20 | 128 | 64 | 1280 | 2.2647613696231015 | 3.2719607095945618 | stage_scale_Y_um_per_step | 3 | True |  | 1.88353
trial | 10x | 10x | 20x | 0.25 | 0.7345409375931375 | 100 | 130 | 20 | 128 | 64 | 1280 | 2.2647613696231015 | 3.2719607095945618 | stage_scale_Y_um_per_step | 4 | True |  | 3.0934
trial | 10x | 10x | 20x | 0.25 | 0.7345409375931375 | 100 | 130 | 20 | 128 | 64 | 1280 | 2.2647613696231015 | 3.2719607095945618 | stage_scale_Y_um_per_step | 5 | True |  | 3.1623
trial | 10x | 10x | 20x | 0.25 | 0.7345409375931375 | 100 | 130 | 20 | 128 | 64 | 1280 | 2.2647613696231015 | 3.2719607095945618 | stage_scale_Y_um_per_step | 6 | True |  | 3.0423
trial | 10x | 10x | 20x | 0.25 | 0.7345409375931375 | 100 | 130 | 20 | 128 | 64 | 1280 | 2.2647613696231015 | 3.2719607095945618 | stage_scale_Y_um_per_step | 7 | True |  | 3.1143
trial | 10x | 10x | 20x | 0.25 | 0.7345409375931375 | 100 | 130 | 20 | 128 | 64 | 1280 | 2.2647613696231015 | 3.2719607095945618 | stage_scale_Y_um_per_step | 8 | True |  | 3.0834
trial | 10x | 10x | 20x | 0.25 | 0.7345409375931375 | 100 | 130 | 20 | 128 | 64 | 1280 | 2.2647613696231015 | 3.2719607095945618 | stage_scale_Y_um_per_step | 9 | True |  | 3.0923
trial | 4x | 4x | 4x | 0.1 | 3.672704687965688 | 100 | 130 | 20 | 803 | 402 | 8030 | 2.2647613696231015 | 3.2719607095945618 | backlash_X_residual_um | 0 | True |  | 1.4565 | 0.9708 | 0.8996
trial | 4x | 4x | 4x | 0.1 | 3.672704687965688 | 100 | 130 | 20 | 803 | 402 | 8030 | 2.2647613696231015 | 3.2719607095945618 | backlash_X_residual_um | 1 | True |  | 2.8401 | 0.9699 | 0.9002
trial | 4x | 4x | 4x | 0.1 | 3.672704687965688 | 100 | 130 | 20 | 803 | 402 | 8030 | 2.2647613696231015 | 3.2719607095945618 | backlash_X_residual_um | 2 | True |  | 4.1223 | 0.9732 | 0.8964
trial | 4x | 4x | 4x | 0.1 | 3.672704687965688 | 100 | 130 | 20 | 803 | 402 | 8030 | 2.2647613696231015 | 3.2719607095945618 | backlash_X_residual_um | 3 | True |  | 0.8229 | 0.9832 | 0.9654
trial | 4x | 4x | 4x | 0.1 | 3.672704687965688 | 100 | 130 | 20 | 803 | 402 | 8030 | 2.2647613696231015 | 3.2719607095945618 | backlash_X_residual_um | 4 | True |  | 0.7402 | 0.9813 | 0.9695
trial | 4x | 4x | 4x | 0.1 | 3.672704687965688 | 100 | 130 | 20 | 803 | 402 | 8030 | 2.2647613696231015 | 3.2719607095945618 | backlash_X_residual_um | 5 | True |  | 0.7259 | 0.9802 | 0.9716
trial | 4x | 4x | 4x | 0.1 | 3.672704687965688 | 100 | 130 | 20 | 803 | 402 | 8030 | 2.2647613696231015 | 3.2719607095945618 | backlash_X_residual_um | 6 | True |  | 4.231 | 0.9731 | 0.7009
trial | 4x | 4x | 4x | 0.1 | 3.672704687965688 | 100 | 130 | 20 | 803 | 402 | 8030 | 2.2647613696231015 | 3.2719607095945618 | backlash_X_residual_um | 7 | True |  | 2.2721 | 0.9871 | 0.7713
trial | 4x | 4x | 4x | 0.1 | 3.672704687965688 | 100 | 130 | 20 | 803 | 402 | 8030 | 2.2647613696231015 | 3.2719607095945618 | backlash_X_residual_um | 8 | True |  | 3.18 | 0.981 | 0.9745
trial | 4x | 4x | 4x | 0.1 | 3.672704687965688 | 100 | 130 | 20 | 803 | 402 | 8030 | 2.2647613696231015 | 3.2719607095945618 | backlash_X_residual_um | 9 | True |  | 4.1168 | 0.9748 | 0.8951
trial | 4x | 4x | 4x | 0.1 | 3.672704687965688 | 100 | 130 | 20 | 803 | 402 | 8030 | 2.2647613696231015 | 3.2719607095945618 | backlash_X_residual_um | 10 | True |  | 1.3557 | 0.9836 | 0.7678
trial | 4x | 4x | 4x | 0.1 | 3.672704687965688 | 100 | 130 | 20 | 803 | 402 | 8030 | 2.2647613696231015 | 3.2719607095945618 | backlash_X_residual_um | 11 | True |  | 1.1815 | 0.9758 | 0.8326
trial | 4x | 4x | 4x | 0.1 | 3.672704687965688 | 100 | 130 | 20 | 803 | 402 | 8030 | 2.2647613696231015 | 3.2719607095945618 | backlash_X_residual_um | 12 | True |  | 0.9093 | 0.9829 | 0.7831
trial | 10x | 10x | 20x | 0.25 | 0.7345409375931375 | 100 | 130 | 20 | 128 | 64 | 1280 | 2.2647613696231015 | 3.2719607095945618 | backlash_X_residual_um | 0 | True |  | 1.587 | 1.039 | 0.977
trial | 10x | 10x | 20x | 0.25 | 0.7345409375931375 | 100 | 130 | 20 | 128 | 64 | 1280 | 2.2647613696231015 | 3.2719607095945618 | backlash_X_residual_um | 1 | True |  | 1.7957 | 1.0343 | 0.9899
trial | 10x | 10x | 20x | 0.25 | 0.7345409375931375 | 100 | 130 | 20 | 128 | 64 | 1280 | 2.2647613696231015 | 3.2719607095945618 | backlash_X_residual_um | 2 | True |  | 1.7957 | 1.0343 | 0.9899
trial | 10x | 10x | 20x | 0.25 | 0.7345409375931375 | 100 | 130 | 20 | 128 | 64 | 1280 | 2.2647613696231015 | 3.2719607095945618 | backlash_X_residual_um | 3 | True |  | 0.4141 | 1.0163 | 0.9605
trial | 10x | 10x | 20x | 0.25 | 0.7345409375931375 | 100 | 130 | 20 | 128 | 64 | 1280 | 2.2647613696231015 | 3.2719607095945618 | backlash_X_residual_um | 4 | True |  | 0.3138 | 1.0131 | 0.9881
trial | 10x | 10x | 20x | 0.25 | 0.7345409375931375 | 100 | 130 | 20 | 128 | 64 | 1280 | 2.2647613696231015 | 3.2719607095945618 | backlash_X_residual_um | 5 | True |  | 0.3138 | 1.0131 | 0.9881
trial | 10x | 10x | 20x | 0.25 | 0.7345409375931375 | 100 | 130 | 20 | 128 | 64 | 1280 | 2.2647613696231015 | 3.2719607095945618 | backlash_X_residual_um | 6 | True |  | 0.6979 | 1.011 | 0.9461
trial | 10x | 10x | 20x | 0.25 | 0.7345409375931375 | 100 | 130 | 20 | 128 | 64 | 1280 | 2.2647613696231015 | 3.2719607095945618 | backlash_X_residual_um | 7 | True |  | 0.2997 | 1.0173 | 0.9914
trial | 10x | 10x | 20x | 0.25 | 0.7345409375931375 | 100 | 130 | 20 | 128 | 64 | 1280 | 2.2647613696231015 | 3.2719607095945618 | backlash_X_residual_um | 8 | True |  | 0.2997 | 1.0173 | 0.9914
trial | 10x | 10x | 20x | 0.25 | 0.7345409375931375 | 100 | 130 | 20 | 128 | 64 | 1280 | 2.2647613696231015 | 3.2719607095945618 | backlash_X_residual_um | 9 | True |  | 0.0542 | 1.0126 | 0.9946
trial | 10x | 10x | 20x | 0.25 | 0.7345409375931375 | 100 | 130 | 20 | 128 | 64 | 1280 | 2.2647613696231015 | 3.2719607095945618 | backlash_X_residual_um | 10 | True |  | 0.0542 | 1.0126 | 0.9946
trial | 10x | 10x | 20x | 0.25 | 0.7345409375931375 | 100 | 130 | 20 | 128 | 64 | 1280 | 2.2647613696231015 | 3.2719607095945618 | backlash_X_residual_um | 11 | True |  | 0.027 | 1.0061 | 0.9947
trial | 10x | 10x | 20x | 0.25 | 0.7345409375931375 | 100 | 130 | 20 | 128 | 64 | 1280 | 2.2647613696231015 | 3.2719607095945618 | backlash_X_residual_um | 12 | True |  | 0.027 | 1.0061 | 0.9947
trial | 4x | 4x | 4x | 0.1 | 3.672704687965688 | 100 | 130 | 20 | 803 | 402 | 8030 | 2.2647613696231015 | 3.2719607095945618 | backlash_Y_residual_um | 0 | True |  | 3.4959 | 0.9812 | 0.9854
trial | 4x | 4x | 4x | 0.1 | 3.672704687965688 | 100 | 130 | 20 | 803 | 402 | 8030 | 2.2647613696231015 | 3.2719607095945618 | backlash_Y_residual_um | 1 | True |  | 4.034 | 0.9701 | 0.9132
trial | 4x | 4x | 4x | 0.1 | 3.672704687965688 | 100 | 130 | 20 | 803 | 402 | 8030 | 2.2647613696231015 | 3.2719607095945618 | backlash_Y_residual_um | 2 | True |  | 0.6851 | 0.9892 | 0.8306
trial | 4x | 4x | 4x | 0.1 | 3.672704687965688 | 100 | 130 | 20 | 803 | 402 | 8030 | 2.2647613696231015 | 3.2719607095945618 | backlash_Y_residual_um | 3 | True |  | 1.3251 | 0.9805 | 0.9069
trial | 4x | 4x | 4x | 0.1 | 3.672704687965688 | 100 | 130 | 20 | 803 | 402 | 8030 | 2.2647613696231015 | 3.2719607095945618 | backlash_Y_residual_um | 4 | True |  | 3.54 | 0.9863 | 0.9647
trial | 4x | 4x | 4x | 0.1 | 3.672704687965688 | 100 | 130 | 20 | 803 | 402 | 8030 | 2.2647613696231015 | 3.2719607095945618 | backlash_Y_residual_um | 5 | True |  | 0.7659 | 0.981 | 0.8512
trial | 4x | 4x | 4x | 0.1 | 3.672704687965688 | 100 | 130 | 20 | 803 | 402 | 8030 | 2.2647613696231015 | 3.2719607095945618 | backlash_Y_residual_um | 6 | True |  | 0.8681 | 0.9801 | 0.9268
trial | 4x | 4x | 4x | 0.1 | 3.672704687965688 | 100 | 130 | 20 | 803 | 402 | 8030 | 2.2647613696231015 | 3.2719607095945618 | backlash_Y_residual_um | 7 | True |  | 0.4672 | 0.9853 | 0.8984
trial | 4x | 4x | 4x | 0.1 | 3.672704687965688 | 100 | 130 | 20 | 803 | 402 | 8030 | 2.2647613696231015 | 3.2719607095945618 | backlash_Y_residual_um | 8 | True |  | 0.4645 | 0.9885 | 0.9445
trial | 4x | 4x | 4x | 0.1 | 3.672704687965688 | 100 | 130 | 20 | 803 | 402 | 8030 | 2.2647613696231015 | 3.2719607095945618 | backlash_Y_residual_um | 9 | True |  | 0.4629 | 0.9901 | 0.914
trial | 10x | 10x | 20x | 0.25 | 0.7345409375931375 | 100 | 130 | 20 | 128 | 64 | 1280 | 2.2647613696231015 | 3.2719607095945618 | backlash_Y_residual_um | 0 | True |  | 1.0932 | 1.0388 | 0.9581
trial | 10x | 10x | 20x | 0.25 | 0.7345409375931375 | 100 | 130 | 20 | 128 | 64 | 1280 | 2.2647613696231015 | 3.2719607095945618 | backlash_Y_residual_um | 1 | True |  | 1.2577 | 1.0314 | 0.9931
trial | 10x | 10x | 20x | 0.25 | 0.7345409375931375 | 100 | 130 | 20 | 128 | 64 | 1280 | 2.2647613696231015 | 3.2719607095945618 | backlash_Y_residual_um | 2 | True |  | 1.2577 | 1.0314 | 0.9931
trial | 10x | 10x | 20x | 0.25 | 0.7345409375931375 | 100 | 130 | 20 | 128 | 64 | 1280 | 2.2647613696231015 | 3.2719607095945618 | backlash_Y_residual_um | 3 | True |  | 0.1504 | 1.0102 | 0.9694
trial | 10x | 10x | 20x | 0.25 | 0.7345409375931375 | 100 | 130 | 20 | 128 | 64 | 1280 | 2.2647613696231015 | 3.2719607095945618 | backlash_Y_residual_um | 4 | True |  | 0.8007 | 1.022 | 0.9941
trial | 10x | 10x | 20x | 0.25 | 0.7345409375931375 | 100 | 130 | 20 | 128 | 64 | 1280 | 2.2647613696231015 | 3.2719607095945618 | backlash_Y_residual_um | 5 | True |  | 0.8007 | 1.022 | 0.9941
trial | 10x | 10x | 20x | 0.25 | 0.7345409375931375 | 100 | 130 | 20 | 128 | 64 | 1280 | 2.2647613696231015 | 3.2719607095945618 | backlash_Y_residual_um | 6 | True |  | 0.0274 | 1.0142 | 0.9567
trial | 10x | 10x | 20x | 0.25 | 0.7345409375931375 | 100 | 130 | 20 | 128 | 64 | 1280 | 2.2647613696231015 | 3.2719607095945618 | backlash_Y_residual_um | 7 | True |  | 0.5895 | 1.0237 | 0.993
trial | 10x | 10x | 20x | 0.25 | 0.7345409375931375 | 100 | 130 | 20 | 128 | 64 | 1280 | 2.2647613696231015 | 3.2719607095945618 | backlash_Y_residual_um | 8 | True |  | 0.5895 | 1.0237 | 0.993
trial | 10x | 10x | 20x | 0.25 | 0.7345409375931375 | 100 | 130 | 20 | 128 | 64 | 1280 | 2.2647613696231015 | 3.2719607095945618 | backlash_Y_residual_um | 9 | True |  | 0.4829 | 1.0236 | 0.9871
trial | 10x | 10x | 20x | 0.25 | 0.7345409375931375 | 100 | 130 | 20 | 128 | 64 | 1280 | 2.2647613696231015 | 3.2719607095945618 | backlash_Y_residual_um | 10 | True |  | 0.4829 | 1.0236 | 0.9871
trial | 10x | 10x | 20x | 0.25 | 0.7345409375931375 | 100 | 130 | 20 | 128 | 64 | 1280 | 2.2647613696231015 | 3.2719607095945618 | backlash_Y_residual_um | 11 | True |  | 0.3755 | 1.0065 | 0.9827
trial | 10x | 10x | 20x | 0.25 | 0.7345409375931375 | 100 | 130 | 20 | 128 | 64 | 1280 | 2.2647613696231015 | 3.2719607095945618 | backlash_Y_residual_um | 12 | True |  | 0.3755 | 1.0065 | 0.9827
summary_mean | 4x | 4x | 4x | 0.1 | 3.672704687965688 | 100 | 130 | 20 | 803 | 402 | 8030 | 2.2647613696231015 | 3.2719607095945618 | stage_scale_X_um_per_step |  |  |  | 2.2319275
summary_std | 4x | 4x | 4x | 0.1 | 3.672704687965688 | 100 | 130 | 20 | 803 | 402 | 8030 | 2.2647613696231015 | 3.2719607095945618 | stage_scale_X_um_per_step |  |  |  | 0.069884229997
summary_n | 4x | 4x | 4x | 0.1 | 3.672704687965688 | 100 | 130 | 20 | 803 | 402 | 8030 | 2.2647613696231015 | 3.2719607095945618 | stage_scale_X_um_per_step |  |  |  | 12
summary_mean | 10x | 10x | 20x | 0.25 | 0.7345409375931375 | 100 | 130 | 20 | 128 | 64 | 1280 | 2.2647613696231015 | 3.2719607095945618 | stage_scale_X_um_per_step |  |  |  | 2.04500545455
summary_std | 10x | 10x | 20x | 0.25 | 0.7345409375931375 | 100 | 130 | 20 | 128 | 64 | 1280 | 2.2647613696231015 | 3.2719607095945618 | stage_scale_X_um_per_step |  |  |  | 0.680989962633
summary_n | 10x | 10x | 20x | 0.25 | 0.7345409375931375 | 100 | 130 | 20 | 128 | 64 | 1280 | 2.2647613696231015 | 3.2719607095945618 | stage_scale_X_um_per_step |  |  |  | 11
summary_mean | 4x | 4x | 4x | 0.1 | 3.672704687965688 | 100 | 130 | 20 | 803 | 402 | 8030 | 2.2647613696231015 | 3.2719607095945618 | stage_scale_Y_um_per_step |  |  |  | 3.147506
summary_std | 4x | 4x | 4x | 0.1 | 3.672704687965688 | 100 | 130 | 20 | 803 | 402 | 8030 | 2.2647613696231015 | 3.2719607095945618 | stage_scale_Y_um_per_step |  |  |  | 0.109815872785
summary_n | 4x | 4x | 4x | 0.1 | 3.672704687965688 | 100 | 130 | 20 | 803 | 402 | 8030 | 2.2647613696231015 | 3.2719607095945618 | stage_scale_Y_um_per_step |  |  |  | 10
summary_mean | 10x | 10x | 20x | 0.25 | 0.7345409375931375 | 100 | 130 | 20 | 128 | 64 | 1280 | 2.2647613696231015 | 3.2719607095945618 | stage_scale_Y_um_per_step |  |  |  | 2.669782
summary_std | 10x | 10x | 20x | 0.25 | 0.7345409375931375 | 100 | 130 | 20 | 128 | 64 | 1280 | 2.2647613696231015 | 3.2719607095945618 | stage_scale_Y_um_per_step |  |  |  | 1.00980113075
summary_n | 10x | 10x | 20x | 0.25 | 0.7345409375931375 | 100 | 130 | 20 | 128 | 64 | 1280 | 2.2647613696231015 | 3.2719607095945618 | stage_scale_Y_um_per_step |  |  |  | 10
summary_mean | 4x | 4x | 4x | 0.1 | 3.672704687965688 | 100 | 130 | 20 | 803 | 402 | 8030 | 2.2647613696231015 | 3.2719607095945618 | backlash_X_residual_um |  |  |  | 2.15033076923
summary_std | 4x | 4x | 4x | 0.1 | 3.672704687965688 | 100 | 130 | 20 | 803 | 402 | 8030 | 2.2647613696231015 | 3.2719607095945618 | backlash_X_residual_um |  |  |  | 1.38464346397
summary_n | 4x | 4x | 4x | 0.1 | 3.672704687965688 | 100 | 130 | 20 | 803 | 402 | 8030 | 2.2647613696231015 | 3.2719607095945618 | backlash_X_residual_um |  |  |  | 13
summary_mean | 10x | 10x | 20x | 0.25 | 0.7345409375931375 | 100 | 130 | 20 | 128 | 64 | 1280 | 2.2647613696231015 | 3.2719607095945618 | backlash_X_residual_um |  |  |  | 0.590753846154
summary_std | 10x | 10x | 20x | 0.25 | 0.7345409375931375 | 100 | 130 | 20 | 128 | 64 | 1280 | 2.2647613696231015 | 3.2719607095945618 | backlash_X_residual_um |  |  |  | 0.67535374387
summary_n | 10x | 10x | 20x | 0.25 | 0.7345409375931375 | 100 | 130 | 20 | 128 | 64 | 1280 | 2.2647613696231015 | 3.2719607095945618 | backlash_X_residual_um |  |  |  | 13
summary_mean | 4x | 4x | 4x | 0.1 | 3.672704687965688 | 100 | 130 | 20 | 803 | 402 | 8030 | 2.2647613696231015 | 3.2719607095945618 | backlash_Y_residual_um |  |  |  | 1.61087
summary_std | 4x | 4x | 4x | 0.1 | 3.672704687965688 | 100 | 130 | 20 | 803 | 402 | 8030 | 2.2647613696231015 | 3.2719607095945618 | backlash_Y_residual_um |  |  |  | 1.46404372206
summary_n | 4x | 4x | 4x | 0.1 | 3.672704687965688 | 100 | 130 | 20 | 803 | 402 | 8030 | 2.2647613696231015 | 3.2719607095945618 | backlash_Y_residual_um |  |  |  | 10
summary_mean | 10x | 10x | 20x | 0.25 | 0.7345409375931375 | 100 | 130 | 20 | 128 | 64 | 1280 | 2.2647613696231015 | 3.2719607095945618 | backlash_Y_residual_um |  |  |  | 0.6372
summary_std | 10x | 10x | 20x | 0.25 | 0.7345409375931375 | 100 | 130 | 20 | 128 | 64 | 1280 | 2.2647613696231015 | 3.2719607095945618 | backlash_Y_residual_um |  |  |  | 0.390449806847
summary_n | 10x | 10x | 20x | 0.25 | 0.7345409375931375 | 100 | 130 | 20 | 128 | 64 | 1280 | 2.2647613696231015 | 3.2719607095945618 | backlash_Y_residual_um |  |  |  | 13

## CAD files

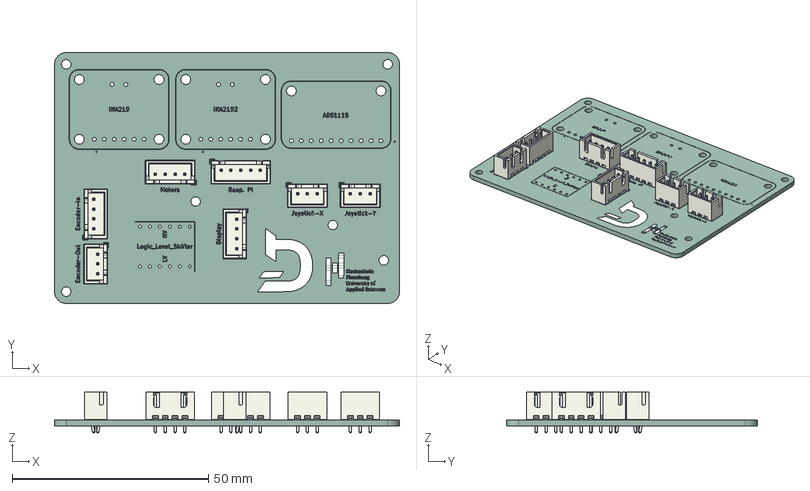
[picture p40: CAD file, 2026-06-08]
cad/pcb/Retroscope.step
88.0 x 64.0 x 10.4 mm
JST_XH_B3B-XH-A_1x03_P2.50mm_Vertical x 3
JST_XH_B4B-XH-A_1x04_P2.50mm_Vertical x 3
JST_XH_B5B-XH-A_1x05_P2.50mm_Vertical
Untitled_silkscreen
Untitled_PCB

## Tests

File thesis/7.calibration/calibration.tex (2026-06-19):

\subsection{Purpose of Calibration}

Calibration turns the motorized retrofit from a movable camera system into a measurement-capable microscope platform. Without calibration, the software can move motors and display images, but it cannot reliably express distances in micrometers, plan tile overlap, or compensate backlash.

The calibration process must address several mappings. Image pixels must be mapped to physical distance at the sample. Motor steps must be mapped to physical stage movement. Focus movement must be related to depth-of-field and autofocus range. Backlash must be measured so that direction changes can be compensated. Soft limits must be configured so that automated moves do not drive the stage or focus axis into unsafe regions.

\subsection{Calibration Wizard Workflow}

RetroScope implements calibration as guided workflows rather than as raw configuration editing. This design is important because the calibration values are meaningful only when measured in the correct order and under controlled conditions.

The calibration wizards are part of the usability contribution. They allow the user to calibrate the microscope through the same application that will later use the calibration values. This reduces the risk that calibration data is recorded externally and then transferred incorrectly. Values are stored in the configuration system and are immediately available to motion control, measurement, autofocus, focus stacking, and tile scanning. Figure~\ref{fig:calibration-flow} shows the order in which the calibrations are performed and how they feed the workflows.

\input{figures/fig_calibration_flow}

\begin{figure}[H]
    \centering
    \begin{subfigure}[t]{0.48\linewidth}
        \centering
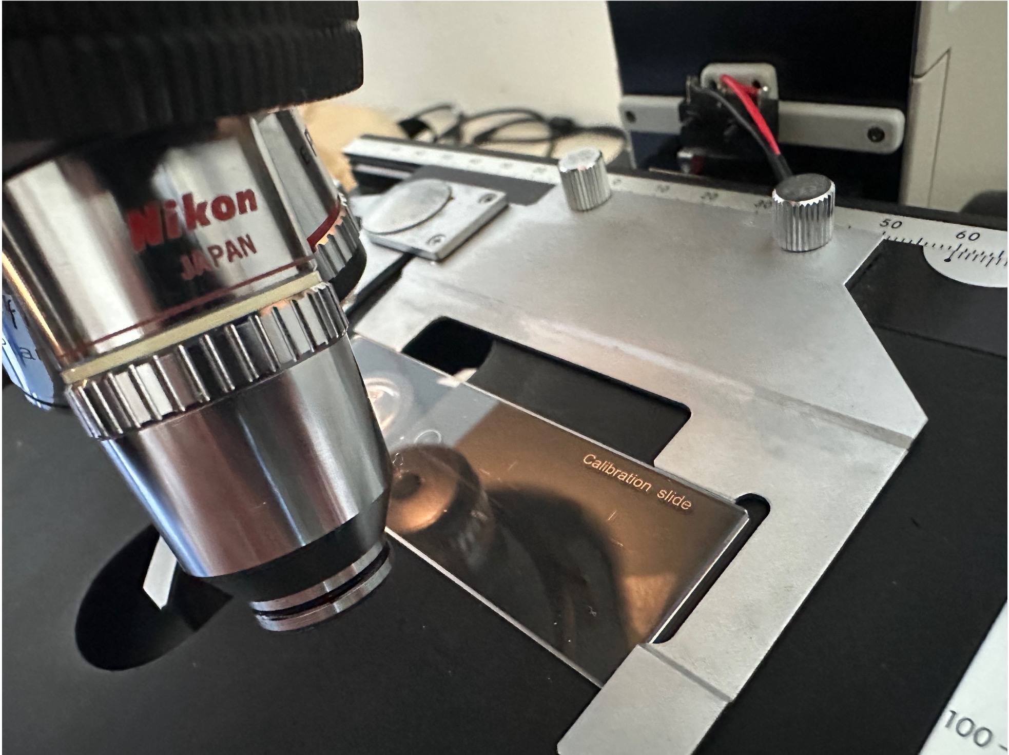
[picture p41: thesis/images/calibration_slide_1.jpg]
        
        \caption{Calibration Slide inserted into the microscope for pixel-scale calibration.}
    \end{subfigure}\hfill
    \begin{subfigure}[t]{0.48\linewidth}
        \centering
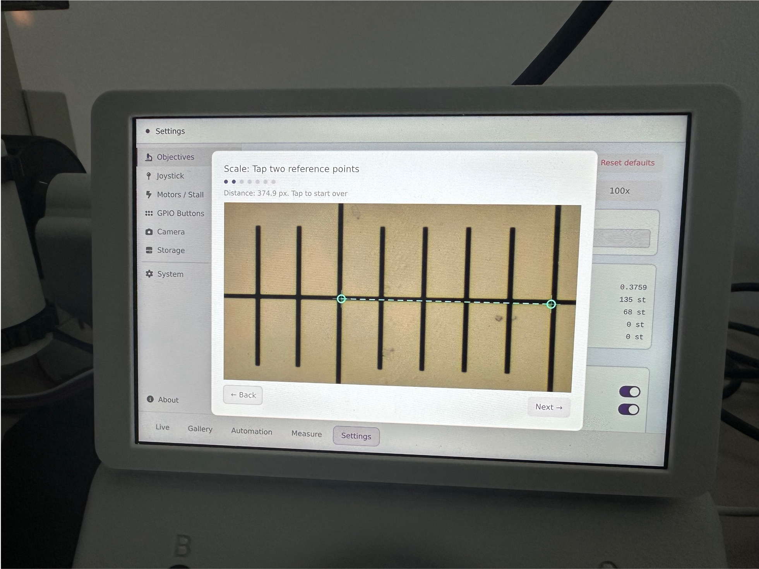
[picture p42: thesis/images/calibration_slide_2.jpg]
        
        \caption{Calibration wizard measuring pixel scale by marking reference points on the calibration slide.}
    \end{subfigure}
    \caption[Pixel-scale calibration workflow]{Calibration process in action: the user inserts a calibration slide and marks reference points to measure pixel scale.The resulting values are stored in the configuration and used by the software.}
    \label{fig:calibration}
\end{figure}

\subsection{Objective Profiles and Pixel Scale Calibration}

Objective profiles store magnification, numerical aperture, backlash values, micrometers per pixel, depth-of-field steps, focus-stack step, and autofocus range. The active objective determines the scale bar, measurement conversion, motion speed, focus-stack spacing, and tile-scan planning.

Pixel-scale calibration measures how many micrometers in the specimen plane correspond to one image pixel for a given objective and camera configuration. This is usually performed using a calibration slide. Once calibrated, distances in the measurement view can be reported in physical units, and tile scans can compute the physical size of the camera field of view.

The default configuration currently stores calibrated micrometers-per-pixel values for several objectives using the Nikon Optiphot 66 microscope and a Nikon DSLR camera.

\begin{table}[H]
    \centering
    \caption[Objective profile calibration values]{Objective profiles in the default configuration: numerical aperture (NA), pixel scale,
    depth-of-field steps, focus-stack step, autofocus search range, and per-axis backlash. The pixel scales for the higher-magnification objectives are derived from the base objective rather than measured directly.}
    \label{tab:objectives}
    \begin{tabular}{@{}l c c c c c c@{}}
        \toprule
        \textbf{Obj.} & \textbf{NA} & \textbf{$\mu$m/px} & \textbf{DoF} & \textbf{Stack} &
        \textbf{AF range} & \textbf{Backlash X/Y/Z} \\
         & & & \textbf{(steps)} & \textbf{(steps)} & \textbf{(steps)} & \textbf{(steps)} \\
        \midrule
        4x   & 0.10 & 3.673 & 803 & 402 & 8030 & 100/200/20 \\
        20x  & 0.40 & 0.735 & 128 & 64  & 1280 & 100/200/20 \\
        40x  & 0.65 & 0.367 & 50  & 25  & 500  & 100/200/20 \\
        63x  & 1.40 & 0.233 & 19  & 10  & 200  & 100/200/20 \\
        100x & 1.25 & 0.147 & 5   & 3   & 200  & 100/200/20 \\
        \bottomrule
    \end{tabular}
\end{table}

\subsection{Scaling Calibration Across Objectives}

During development, direct calibration on high-magnification objectives was found to be difficult. The calibration was reworked so that one base objective can be calibrated and other objective scales can be derived from magnification. The relationship used for pixel scale is:

\[
    s_{\mathrm{target}} = s_{\mathrm{base}} \cdot \frac{M_{\mathrm{base}}}{M_{\mathrm{target}}},
\]

where \(s\) is the micrometers-per-pixel scale and \(M\) is magnification. For example, if a 4x objective has a scale of \(2.0\,\mu\mathrm{m/px}\), a 10x objective is estimated as \(2.0 \cdot 4 / 10 = 0.8\,\mu\mathrm{m/px}\).

Depth-of-field related steps are scaled from the optical dependence of axial depth of field on numerical aperture. A microscope objective's total depth of field can be approximated as the sum of a diffraction term and a detector/magnification term \cite{nikonDepthField}:

\[
    d_{\mathrm{tot}} =
    \frac{\lambda \cdot n}{NA^2} + \frac{n }{M \cdot NA} e,
\]

where \(\lambda\) is the illumination wavelength, \(n\) is the refractive index of the medium between specimen and objective, \(NA\) is numerical aperture, \(M\) is objective magnification, and \(e\) is the smallest resolvable distance at the detector. The first term shows the inverse-square dependence on numerical aperture. RetroScope uses this as a practical calibration approximation: the base objective is measured directly, and the motor-step counts for focus-stack spacing, depth-of-field stepping, and autofocus range are derived by scaling the calibrated base value with the relative inverse-square NA ratio:

\[
    d_{\mathrm{target}} = d_{\mathrm{base}} \cdot
    \left(\frac{NA_{\mathrm{base}}}{NA_{\mathrm{target}}}\right)^2.
\]

Here \(d\) denotes a motor-step count derived from the calibrated base objective rather than an optical distance in micrometers.

This approach makes calibration practical across several objectives, but it also introduces assumptions. Magnification and numerical aperture give useful scaling, but they do not account for all optical and mechanical differences. Direct measurement remains preferable where high accuracy is required.

\subsection{Stage Scale Calibration for X and Y}

Stage-scale calibration measures how far the sample moves per motor step in X and Y. This is different from pixel-scale calibration. Pixel scale maps the image to the specimen plane, while stage scale maps motor commands to physical movement. Both are required for tile scans because the tile planner must know how many motor steps move the field of view by a desired physical overlap.

The system stores X and Y stage scales separately because the axes can differ mechanically. The stage scale is measured per axis with the following procedure: a textured reference region is captured, the axis is commanded a known number of motor steps in a fixed direction, a second frame is captured, and the image displacement is measured. Image-registration methods such as phase correlation are established tools for estimating translational displacement between images \cite{guizar2008subpixel}. The scale follows directly from the pixel displacement and the calibrated pixel scale,
\[
    \mathrm{stage\ scale} \;=\; \frac{\Delta_{\mathrm{px}}\cdot s}{N_{\mathrm{steps}}}
    \quad\left[\frac{\mu\mathrm{m}}{\mathrm{step}}\right],
\]
where $\Delta_{\mathrm{px}}$ is the measured displacement, $s$ the pixel scale, and $N_{\mathrm{steps}}$ the commanded steps. To assess repeatability the measurement is repeated several times per axis and reported in Table~\ref{tab:stagescale-protocol}.

\begin{table}[H]
    \centering
    \caption[Measured 4x stage-scale repeatability]{Measured 4x stage-scale repeatability from the evaluation. Values are mean
    $\pm$ standard deviation across 10 valid trials.}
    \label{tab:stagescale-protocol}
    \begin{tabular}{@{}l c c c c@{}}
        \toprule
        \textbf{Axis} & \textbf{Commanded steps} & \textbf{Valid trials} &
        \textbf{Measured px} & \textbf{$\mu$m/step} \\
        \midrule
        X & 100 & 10 & $59.44 \pm 2.59$ & $2.183 \pm 0.095$ \\
        X & 200 & 10 & $121.05 \pm 3.13$ & $2.223 \pm 0.058$ \\
        Y & 100 & 10 & $92.84 \pm 6.48$ & $3.410 \pm 0.238$ \\
        Y & 200 & 10 & $170.76 \pm 3.62$ & $3.136 \pm 0.066$ \\
        \bottomrule
    \end{tabular}
\end{table}

\subsection{Backlash Calibration}

Backlash calibration measures the lost motion that occurs when an axis changes direction. The backlash values are stored per axis and applied through the motion controller's slack model. The calibration process uses image comparison: the user captures a reference crop, moves the axis, reverses direction, and measures the image offset after motion. This connects mechanical slack to visible image displacement.

Backlash existed on all axes, including the Z axis. The Z motor is coupled directly to the fine-focus axis, while X and Y are driven through the printed gearbox and knob interface. Therefore, no additional gearbox backlash is introduced on Z, and the configured Z backlash is smaller than the X and Y values. The value for the Z backlash gets input manually in addition to the measured X and Y backlash.

\subsection{Soft Limits}

Soft limits protect the microscope during manual and automated movement. They are especially important for tile scanning and focus stacking, where the software can issue many moves without direct human attention. The endstop provides a physical safety signal for Z movement, while configured soft limits constrain the XY stage range in software.

During calibration, the user first homes the stage at the top-left corner and then moves to the opposite bottom-right corner. The controller normalizes these two positions into an allowed XY rectangle and saves it in the configuration. Manual moves, joystick movement, live-view tap movement, and automation targets are checked against this rectangle before they are accepted and tile scans are preflighted before capturing starts. Because these limits rely on the controller's open-loop step position, they must be recalibrated if the stage is moved by hand, steps are missed, or the mechanical setup changes.

\subsection{Calibration Limitations}

The calibration process does not eliminate the limitations of the retrofit hardware. It assumes that the mechanical system remains stable after calibration. If printed parts flex differently over time, gears loosen, the stage is moved by hand, the camera resolution changes, or the objective/camera path changes, calibration values may become invalid. The derived scaling between objectives is also an approximation.

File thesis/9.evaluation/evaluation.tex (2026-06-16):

\subsection{Evaluation Setup}

The evaluation examines RetroScope as an integrated retrofit platform rather than as isolated components. The measured prototype consists of the printed mechanical adapter, Raspberry Pi-based embedded electronics, custom PCB, Sangaboard-controlled stepper motors, camera capture path, QML interface, calibration workflow, motion controller, and automated workflows. The physical target microscope is the Nikon Optiphot 66 used throughout development.

The evaluation data covers four experiment types: stage-scale repeatability, motion accuracy, calibration repeatability, and workflow reliability. The stage-scale, motion-accuracy, and reported calibration-repeatability measurements were performed on the 4x objective. Workflow reliability was measured for the 4x, 20x, 40x, and 63x profiles. Figure~\ref{fig:eval-evidence-map} summarizes how the available evidence maps to the research questions.

\input{figures/fig_eval_evidence_map}

\begin{table}[H]
    \centering
    \caption[Evaluation setup]{Evaluation setup and available measurement scope.}
    \label{tab:setup}
    \begin{tabular}{@{}l L{8.2cm}@{}}
        \toprule
        \textbf{Item} & \textbf{Value} \\
        \midrule
        Microscope & Nikon Optiphot 66 vintage microscope \\
        Camera / capture & Nikon DSLR camera via Elgato Cam Link (UVC) \\
        Software stack & Python/PySide6/QML, OpenCV, tifffile \\
        Motion / stage-scale dataset & 4x objective, 100 and 200 step X/Y moves \\
        Calibration-repeat dataset & 4x objective profile \\
        Workflow dataset & 4x, 20x, 40x, and 63x objective profiles \\
        Dataset date & 2026-06-10 \\
        Software commit & 13ada32 \\
        \bottomrule
    \end{tabular}
\end{table}

\subsection{Parametric Adapter Adaptability}

The parametric adapter design provides design-level evidence for adaptability. The Fusion archive contains a model with explicit parameters for microscope feet positions, focus-axis geometry, Z-assembly dimensions, and XY-assembly offsets.

This supports the claim that the adapters are not a static design for a specific microscope. The design process exposed dimensions as adjustable parameters. Because only one suitable vintage instrument was available, and building a second physical prototype was out of scope for time and cost reasons, adaptability is evaluated virtually: the parametric Fusion model is edited to represent a different body dimension, and the adapter geometry regenerates accordingly without rebuilding the assembly. Figure~\ref{fig:virtual-adapt} shows such virtual variants. This is design-level rather than physical evidence, a second physical body validation remains future work.

\input{figures/fig_virtual_adapt}

\begin{table}[H]
    \centering
    \caption[Adapter adaptability parameters]{Adapter adaptability: parameter values for the Nikon Optiphot 66 development body versus a
    virtual variant (right column read off an adapted CAD model, not a physical microscope).}
    \label{tab:adaptability}
    \begin{tabular}{@{}l c c@{}}
        \toprule
        \textbf{Parameter} & \textbf{Nikon Optiphot 66} & \textbf{Virtual variant} \\
        \midrule
        \texttt{connector\_hole\_front\_x/y} & 10 / 10\,mm & 30 / 20\,mm \\
        \texttt{connector\_hole\_back\_x/y}  & 14.5 / 25.5\,mm & 30 / 15\,mm \\
        \texttt{connector\_hole\_front/back\_radius} & 13 / 18\,mm & 32 / 8\,mm \\
        \texttt{focus\_axis\_z} / \texttt{focus\_axis\_radius} & 137 / 17\,mm & 147 / 7\,mm \\
        \texttt{z\_assembly\_height} & 137\,mm & 147\,mm \\
        \texttt{z\_assembly\_x/z\_offset} & 0 / 0\,mm & 60 / 42\,mm \\
        \bottomrule
    \end{tabular}
\end{table}

\subsection{Hardware Cost and Reproducibility}

The prototype uses accessible components: Raspberry Pi, DSI display, Elgato Cam Link, Sangaboard, 28BYJ stepper motors, joystick, ADS1115, rotary encoder, buttons, endstop, and printed parts. The priced bill of materials in Appendix~\ref{app:bom} gives a total component cost of approximately 419,47~\euro, excl. microscope and camera. This value includes the purchased input devices, custom PCB manufacturing, wiring and connectors, and estimated print material, but it does not represent a universal retail price because supplier prices and availability vary. The largest cost drivers are the Raspberry Pi, DSI touchscreen, and HDMI capture adapter. The actual motion parts are comparatively inexpensive. The KiCad project, Gerber files, Fusion export, and parametric printed parts therefore support reproducibility. The hardware can be rebuilt from the repository artifacts.

\subsection{Stage-Scale Repeatability}

Stage-scale repeatability measures how consistently a motor step maps to specimen-plane movement.
The stage-scale evaluation results contains ten valid repetitions with a 4x objective. The results are reported
in Table~\ref{tab:stagescale} and visualized in Figure~\ref{fig:eval-stage-scale}.

\input{figures/fig_eval_stage_scale}

\begin{table}[H]
    \centering
    \caption[4x stage-scale repeatability]{4x stage-scale repeatability. Values are mean $\pm$ standard deviation across valid
    trials.}
    \label{tab:stagescale}
    \begin{tabular}{@{}l c c c@{}}
        \toprule
        \textbf{Axis} & \textbf{Commanded steps} & \textbf{Valid trials} &
        \textbf{Stage scale ($\mu$m/step)} \\
        \midrule
        X & 100 & 10 & $2.183 \pm 0.095$ \\
        X & 200 & 10 & $2.223 \pm 0.058$ \\
        Y & 100 & 10 & $3.410 \pm 0.238$ \\
        Y & 200 & 10 & $3.136 \pm 0.066$ \\
        \bottomrule
    \end{tabular}
\end{table}

The 200-step trials are the most stable subset: X varies by approximately
$0.058\,\mu$m/step and Y by approximately $0.066\,\mu$m/step. The 100-step Y measurement has a
higher spread, which is expected because smaller commanded displacements make image-measurement
noise and mechanical slack more visible. The measured X and Y scales differ substantially, so the
separate per-axis stage-scale calibration is justified.

\subsection{Motion Accuracy and Backlash Compensation}

Motion accuracy was evaluated with X/Y moves at 100 and 200 motor steps on a 4x objective. The comparison includes
uncompensated movement, a sign-based compensation mode, and the hysteresis-band
compensation model. The mean forward error compares measured optical displacement with the commanded
physical displacement. The reversal residual measures the remaining image offset after commanding a
return move. Table~\ref{tab:motion} and Figure~\ref{fig:eval-motion} summarize the valid trial
rows.

\input{figures/fig_eval_motion}

The strongest motion result is the 4x X-axis 200-step condition. In that case, the hysteresis model reduces the mean forward error from $-204.3\,\mu$m without compensation to
$11.4\,\mu$m, while the reversal residual remains lower than the sign-compensated condition. The Y-axis data is less clean: hysteresis reduces the 200-step forward error compared with the other modes, but the residual remains higher than in the uncompensated return measurement, and the 100-step condition overshoots. This matches the mechanical observations from development, where the Y drive showed more flex and backlash, because the 3d printed gears has a longer distance between motor and the knob. The distance is a results of the space constraints and stacked knob design of the target microscope. The data supports the need for compensation, but it also shows that software compensation does not fully remove mechanical limitations.

Another observation is that the 100-step conditions have higher spread and more overshoot than the 200-step conditions, reason for that is that the configured backlash is higher than the commanded 100-step displacement.

\begin{table}[H]
    \centering
    \caption[4x motion accuracy and reversal residuals]{Motion accuracy and reversal residuals on a 4x objective. Values are mean $\pm$ standard deviation in micrometers.}
    \label{tab:motion}
    \begin{adjustbox}{max width=\linewidth}
    \begin{tabular}{l c l c c c}
        \toprule
        \textbf{Axis} & \textbf{Steps} & \textbf{Mode} & \textbf{Valid trials} &
        \textbf{Forward error ($\mu$m)} & \textbf{Reversal residual ($\mu$m)} \\
        \midrule
        X & 100 & none       & 10 & $-165.4 \pm 68.7$ & $40.0 \pm 78.7$ \\
        X & 100 & sign       & 10 & $-61.7 \pm 102.2$ & $119.2 \pm 109.6$ \\
        X & 100 & hysteresis & 10 & $63.2 \pm 56.0$ & $41.5 \pm 45.1$ \\
        X & 200 & none       & 10 & $-204.3 \pm 10.8$ & $0.9 \pm 0.7$ \\
        X & 200 & sign       & 10 & $-30.4 \pm 58.5$ & $44.8 \pm 55.5$ \\
        X & 200 & hysteresis & 10 & $11.4 \pm 2.9$ & $0.3 \pm 0.2$ \\
        Y & 100 & none       & 10 & $-264.7 \pm 33.6$ & $48.4 \pm 104.5$ \\
        Y & 100 & sign       & 10 & $-186.9 \pm 74.7$ & $229.4 \pm 96.1$ \\
        Y & 100 & hysteresis & 10 & $165.5 \pm 64.0$ & $51.6 \pm 49.4$ \\
        Y & 200 & none       & 10 & $-260.1 \pm 18.5$ & $2.1 \pm 2.8$ \\
        Y & 200 & sign       & 10 & $-60.6 \pm 83.0$ & $90.4 \pm 107.4$ \\
        Y & 200 & hysteresis & 10 & $-35.8 \pm 16.4$ & $52.6 \pm 1.7$ \\
        \bottomrule
    \end{tabular}
    \end{adjustbox}
\end{table}

\subsection{Calibration Consistency}

Calibration consistency was evaluated by repeating stage-scale and backlash-residual measurements for the 4x objective profile. The results are listed in Table~\ref{tab:calib-repeat} and shown in Figure~\ref{fig:eval-calibration}.

\input{figures/fig_eval_calibration}

\begin{table}[H]
    \centering
    \caption[4x calibration repeatability]{Calibration repeatability for the 4x objective profile. Values are mean $\pm$
    standard deviation. Stage-scale rows are reported in $\mu$m/step and backlash rows as residual
    displacement in $\mu$m.}
    \label{tab:calib-repeat}
    \begin{tabular}{@{}l l c c@{}}
        \toprule
        \textbf{Objective} & \textbf{Quantity} & \textbf{Valid trials} & \textbf{Value} \\
        \midrule
        4x  & Stage scale X & 10 & $2.232 \pm 0.070$ \\
        4x  & Stage scale Y & 10 & $3.148 \pm 0.110$ \\
        4x  & Backlash residual X & 10 & $2.150 \pm 1.385$ \\
        4x  & Backlash residual Y & 10 & $1.611 \pm 1.464$ \\
        \bottomrule
    \end{tabular}
\end{table}

The 4x stage-scale repeatability is consistent with the dedicated stage-scale experiment and shows that the base objective can be calibrated with a stable pixel-to-motion relationship under the tested conditions. The X-axis stage-scale estimate has a smaller spread than the Y-axis estimate, while both backlash-residual rows remain more variable than the stage-scale rows. This is expected because the backlash check combines the calibrated image scale with a direction reversal, so it is more sensitive to remaining mechanical slack, gear compliance, and image-registration uncertainty.

\subsection{Automated Workflow Reliability}

Workflow reliability was evaluated by running autofocus, focus stacking, and tile scanning ten times for each available objective profile. All 120 workflow trials completed successfully. Autofocus duration was recorded by the evaluation. Focus-stacking and tile-scanning durations were not recorded, so they are reported only as success counts. Table~\ref{tab:workflow} and Figure~\ref{fig:eval-workflow} summarize the results.

\input{figures/fig_eval_workflow}

\begin{table}[H]
    \centering
    \caption[Workflow reliability summary]{Workflow reliability. Autofocus duration is reported as mean $\pm$ standard deviation. Focus stacking and tile scanning are reported as success counts out of 10 trials.}
    \label{tab:workflow}
    \begin{tabular}{@{}l c c c c@{}}
        \toprule
        \textbf{Objective} & \textbf{Autofocus} & \textbf{Focus stacking} &
        \textbf{Tile scanning} & \textbf{Autofocus duration (s)} \\
        \midrule
        4x  & 10/10 & 10/10 & 10/10 & $59.84 \pm 0.49$ \\
        20x & 10/10 & 10/10 & 10/10 & $17.59 \pm 0.31$ \\
        40x & 10/10 & 10/10 & 10/10 & $14.66 \pm 0.17$ \\
        63x & 10/10 & 10/10 & 10/10 & $14.21 \pm 0.07$ \\
        \bottomrule
    \end{tabular}
\end{table}

These workflow results are a quantitative evidence that show that the calibrated prototype can repeatedly complete the three user-facing automated workflows under the tested conditions. The longer 4x autofocus duration is consistent with the larger configured autofocus search range for the lower-magnification objective. The evaluation does not quantify focus-stack quality, tile alignment quality, or workflow duration for stacking and scanning.

\subsection{Summary of Evaluation Results}

The measured results support three conclusions. First, the stage-scale data confirms that the 4x X and Y axes require separate calibration and that 200-step measurements are more stable than 100-step measurements. Second, the motion-accuracy data shows that backlash compensation can substantially improve low-cost open-loop motion, especially X at 200 steps, but it also exposes remaining mechanical variability on Y. Third, the workflow reliability data shows repeatable successful execution of autofocus, focus stacking, and tile scanning across the tested objective profiles.

The evaluation therefore supports RetroScope as a working low-cost retrofit prototype, not as a precision instrument. The main remaining evidence gaps are physical validation on additional microscope bodies, workflow quality metrics motion, and stage-scale/calibration/motion-accuracy measurements with other objectives profiles.

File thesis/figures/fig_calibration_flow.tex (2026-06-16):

\begin{figure}[H]
    \centering
    \begin{tikzpicture}[font=\footnotesize, >=Latex, node distance=4mm,
        cstep/.style={draw, rounded corners, align=center, text width=0.72\linewidth,
                     minimum height=0.8cm, fill=gray!8}]
        \node[cstep] (px)   {\textbf{Pixel-scale calibration} (base objective (e.g. 4x), calibration slide)\\
                             calculates $\mu$m/pixel};
        \node[cstep, below=of px]   (derive) {\textbf{Derive other objectives}\\
                             scale by magnification ($M$) and numerical aperture ($NA$)};
        \node[cstep, below=of derive] (stage) {\textbf{Stage-scale calibration} (X and Y separately)\\
                             calculates $\mu$m/step per axis};
        \node[cstep, below=of stage] (back) {\textbf{Backlash calibration} (per axis, image comparison)\\
                              calculates backlash steps per axis};
        \node[cstep, below=of back] (focus) {\textbf{Depth-of-field (focus stacking)}\\
                             step spacing, search range};
        \draw[-{Latex}] (px)--(derive); \draw[-{Latex}] (derive)--(stage);
        \draw[-{Latex}] (stage)--(back); \draw[-{Latex}] (back)--(focus);
    \end{tikzpicture}
    \caption[Calibration workflow]{Calibration workflow. A base objective is calibrated against a slide, remaining objectives
    are derived from magnification and numerical aperture, and the stage scale, backlash, focus
    parameters, and soft limits are measured and stored in the configuration for reuse by the
    automated workflows.}
    \label{fig:calibration-flow}
\end{figure}

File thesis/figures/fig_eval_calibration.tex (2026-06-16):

\begin{figure}[H]
    \centering
    \begin{tikzpicture}
        \begin{axis}[
            width=\linewidth,
            height=6.4cm,
            ybar,
            bar width=14pt,
            ymin=0,
            ylabel={$\mu$m/step or $\mu$m residual},
            symbolic x coords={4xSX,4xSY,4xBX,4xBY},
            xtick=data,
            xticklabels={4xSX,4xSY,4xBX,4xBY},
            x tick label style={rotate=45, anchor=east, font=\scriptsize},
            error bars/y dir=both, error bars/y explicit,
            grid=major,
            major grid style={draw=gray!25},
        ]
        \addplot+[fill=orange!50, draw=orange!80!black] coordinates {
(4xSX,2.2319) +- (0,0.0699)
(4xSY,3.1475) +- (0,0.1098)
(4xBX,2.1503) +- (0,1.3846)
(4xBY,1.6109) +- (0,1.4640)
        };
        \end{axis}
    \end{tikzpicture}
    \caption[4x calibration-repeatability results]{Calibration-repeatability results for the 4x objective profile. SX/SY are repeated stage-scale estimates. BX/BY are residual displacements after backlash reversal checks. Error bars show one standard deviation.}
    \label{fig:eval-calibration}
\end{figure}

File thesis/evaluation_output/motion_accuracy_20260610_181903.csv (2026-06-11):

row_type | objective_slot | objective_name | objective_display_name | objective_numerical_aperture | objective_um_per_pixel | objective_backlash_x | objective_backlash_y | objective_backlash_z | objective_dof_steps | objective_focus_stack_step | objective_autofocus_range_steps | stage_um_per_step_x | stage_um_per_step_y | axis | mode | commanded_steps | rep | valid | reason | fwd_px | dx_px | dy_px | cross_axis_px | phase_response | template_score | measured_um | commanded_um | error_um | residual_px | residual_um | residual_phase_response
trial | 4x | 4x | 4x | 0.1 | 3.672704687965688 | 100 | 130 | 20 | 803 | 402 | 8030 | 2.264761369623101 | 3.2719607095945618 | X | none | 100 | 0 | True |  | 62.787 | -62.787 | -1.533 | 1.533 | 0.8549 | 0.7074 | 230.5984 | 226.4761 | 4.1222 | 54.728 | 200.9983 | 0.8706
trial | 4x | 4x | 4x | 0.1 | 3.672704687965688 | 100 | 130 | 20 | 803 | 402 | 8030 | 2.264761369623101 | 3.2719607095945618 | X | none | 100 | 1 | True |  | 6.864 | -6.864 | -0.652 | 0.652 | 0.9703 | 0.9399 | 25.2095 | 226.4761 | -201.2666 | 0.999 | 3.6707 | 0.9718
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

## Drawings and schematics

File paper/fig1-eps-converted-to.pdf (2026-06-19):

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

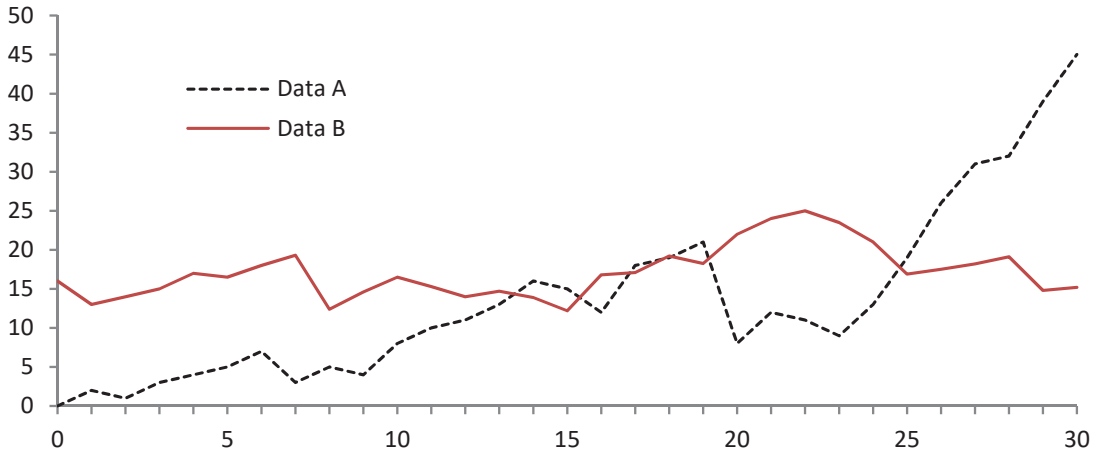
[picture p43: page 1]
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

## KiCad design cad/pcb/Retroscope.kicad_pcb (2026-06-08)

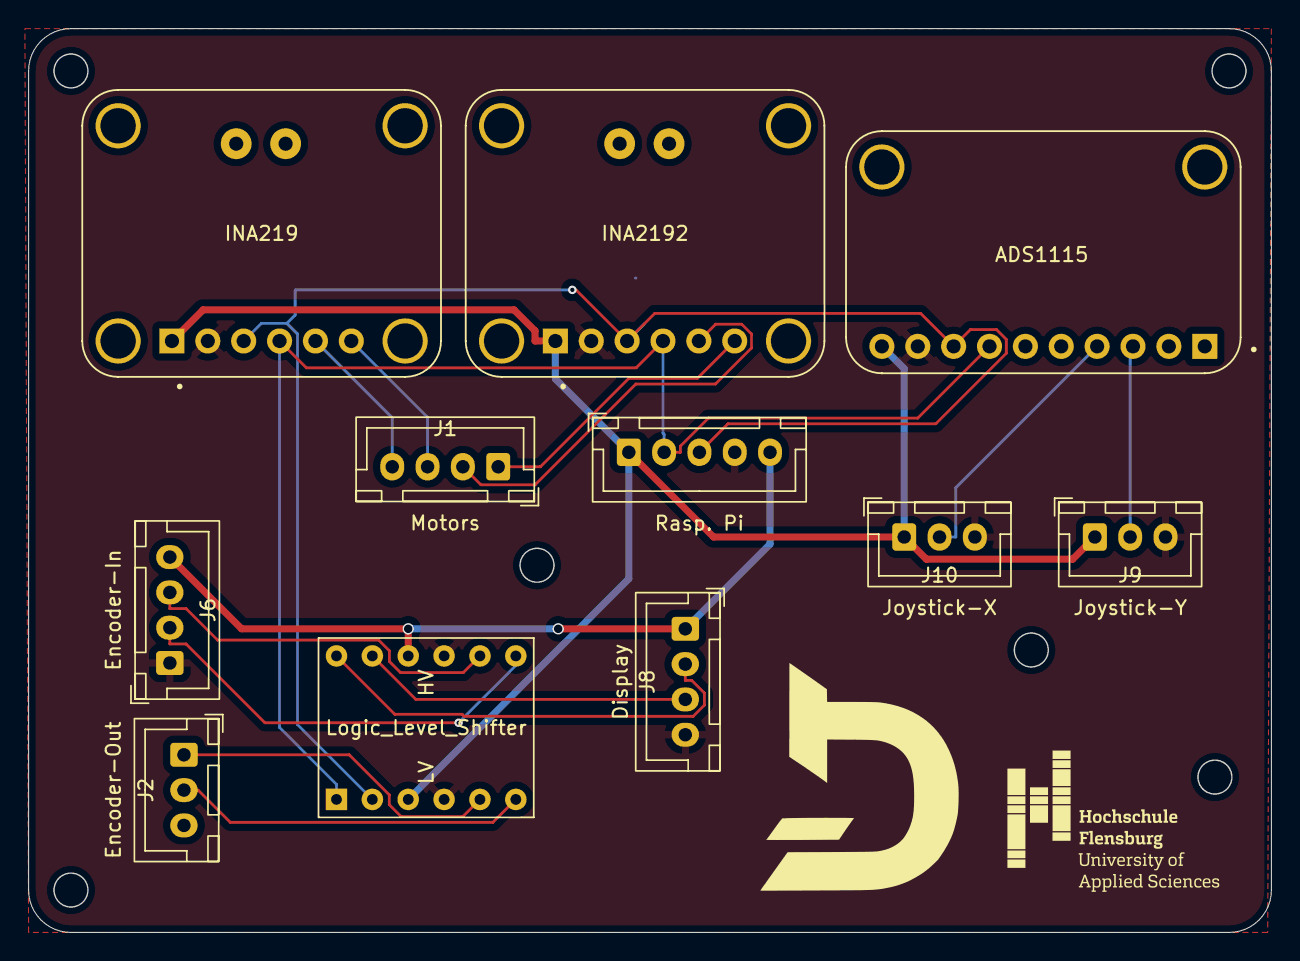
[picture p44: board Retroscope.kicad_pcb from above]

Board: 2 copper layers, 88.0 x 64.0 mm, 11 parts (0 on the bottom side), 19 nets.

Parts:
A1: Logic_Level_Shifter; LogicLevelConverter_Module
ADS1115: ZC261500; MODULE_ZC261500
INA219, INA2192: INA219; MODULE_INA219
J1: Motors; JST_XH_B4B-XH-A_1x04_P2.50mm_Vertical
J2: Encoder-Out; JST_XH_B3B-XH-A_1x03_P2.50mm_Vertical
J6: Encoder-In; JST_XH_B4B-XH-A_1x04_P2.50mm_Vertical
J7: Rasp. Pi; JST_XH_B5B-XH-A_1x05_P2.50mm_Vertical
J8: Display; JST_XH_B4B-XH-A_1x04_P2.50mm_Vertical
J9: Joystick-Y; JST_XH_B3B-XH-A_1x03_P2.50mm_Vertical
J10: Joystick-X; JST_XH_B3B-XH-A_1x03_P2.50mm_Vertical

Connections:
+3.3V: A1.3 (LV), ADS1115.10 (VDD), INA219.1 (VCC), INA2192.1 (VCC), J7.1, J9.1, J10.1
+5V: A1.10 (HV), J6.4, J7.5, J8.1
GND: A1.4 (GND), A1.9 (GND), ADS1115.9 (GND), INA219.2 (GND), INA2192.2 (GND), J6.1, J7.4, J8.4, J9.3, J10.3
unnamed: A1.12 (HV1), J8.2
unnamed: A1.11 (HV2), J8.3
unnamed: A1.8 (HV3), J6.3
unnamed: A1.7 (HV4), J6.2
unnamed: A1.1 (LV1), ADS1115.7 (SDA), INA219.4 (SDA), INA2192.4 (SDA), J7.2
unnamed: A1.2 (LV2), ADS1115.8 (SCL), INA219.3 (SCL), INA2192.3 (SCL), J7.3
unnamed: A1.5 (LV3), J2.1
unnamed: A1.6 (LV4), J2.2
unnamed: INA2192.6 (VIN+), INA2192.VIN+, J1.1
unnamed: INA2192.5 (VIN-), INA2192.VIN-, J1.2
unnamed: INA219.6 (VIN+), INA219.VIN+, J1.3
unnamed: INA219.5 (VIN-), INA219.VIN-, J1.4
unnamed: ADS1115.3 (A1), J9.2
unnamed: ADS1115.4 (A0), J10.2
unnamed: INA2192.SH1 (SHIELD), INA2192.SH2 (SHIELD), INA2192.SH3 (SHIELD), INA2192.SH4 (SHIELD)
unnamed: INA219.SH1 (SHIELD), INA219.SH2 (SHIELD), INA219.SH3 (SHIELD), INA219.SH4 (SHIELD)

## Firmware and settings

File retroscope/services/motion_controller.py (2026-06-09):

"""Motion controller: Translates joystick/encoder input into Sangaboard moves.

Applies joystick dead-zone, exponential curve and objective speed limits.
Guards against endstop to prevent focus motor crashing into stage.

Note: Partially AI-generated (_dispatch_joystick_at, )
"""

import math
import time
from dataclasses import dataclass

from PySide6.QtCore import QCoreApplication, QObject, Property, QTimer, Signal, Slot

from retroscope.services.config_store import CONFIG_RESET_KEY
from retroscope.services.objective_manager import ObjectiveManager

DEADZONE = 0.05                     # inner dead-zone
ADC_MAX = 32767                     # ADS1115 full-scale positive value
ADC_UNIPOLAR_MAX_3V3 = 26400.0      # ADS volt range with a 3.3V joystick input
ENCODER_TRIGGER_UNITS = 50          # only move when this many encoder steps accumulated

_CALIBRATION_Z_ENCODER_STEP = 50    # Fixed Z motor steps per encoder trigger while a DoF calibration is active.
_STAGE_UM_PER_STEP_FALLBACK = 1.0   # used when stage hasn't been alibrate yet
_CALIBRATION_SAMPLES = 30
_BLOCK_REPEAT_S = 0.8
_AXIS_MIN_SPAN = 2048.0
_AXIS_INITIAL_SPAN = 8192.0
_JOYSTICK_PAN_COMMAND_BOOST = 10.0
_JOYSTICK_RELEASE_FACTOR = 0.70
_JOYSTICK_MAX_DISPATCH_DT_S = 0.25
_JOYSTICK_SAMPLE_TIMEOUT_S = 0.15


@dataclass(frozen=True)
class JoystickDispatchParams:
    interval_ms: int
    min_command_steps: int
    force_command_ms: int
    target_alpha: float

    @property
    def interval_s(self) -> float:
        return self.interval_ms / 1000.0

    @property
    def force_command_s(self) -> float:
        return self.force_command_ms / 1000.0


def joystick_dispatch_params() -> JoystickDispatchParams:
    """Return fixed low-latency joystick dispatch parameters."""
    return JoystickDispatchParams(
        interval_ms=25,
        min_command_steps=1,
        force_command_ms=50,
        target_alpha=0.90,
    )


class JoystickAxisNormalizer:
    """Normalizes one joystick axis using per-side spans."""

    def __init__(self) -> None:
        self._center: float | None = None
        self._low_span = _AXIS_MIN_SPAN
        self._high_span = _AXIS_MIN_SPAN

    def set_center(self, center: float | None) -> None:
        self._center = None if center is None else float(center)
        if self._center is None:
            self._low_span = _AXIS_MIN_SPAN
            self._high_span = _AXIS_MIN_SPAN
        else:
            self._low_span = _AXIS_INITIAL_SPAN
            self._high_span = _AXIS_INITIAL_SPAN

    def normalize(self, raw: float) -> float:
        if self._center is None:
            return 0.0
        raw = max(-float(ADC_MAX), min(float(ADC_MAX), float(raw)))
        delta = raw - self._center

        if delta >= 0.0:
            if delta > self._high_span:
                self._high_span = delta
            span = self._high_span
        else:
            low_delta = -delta
            if low_delta > self._low_span:
                self._low_span = low_delta
            span = self._low_span
        return max(-1.0, min(1.0, delta / span))

    @property
    def center(self) -> float | None:
        return self._center


def _joystick_curve(
    value: float,
    deadzone: float = DEADZONE,
    curve: str = "exponential",
    expo_strength: int = 70,
) -> float:
    """Apply dead-zone and selected response curve to a normalized axis value."""
    v = max(-1.0, min(1.0, value))
    sign = 1.0 if v >= 0 else -1.0
    abs_v = abs(v)
    if abs_v < deadzone:
        return 0.0
    normed = (abs_v - deadzone) / (1.0 - deadzone)
    if curve == "linear":
        shaped = normed
    elif curve == "scurve":
        shaped = normed * normed * (3.0 - 2.0 * normed)
    else:
        expo = max(0, min(100, int(expo_strength))) / 100.0
        shaped = normed ** (1.0 + expo * 2.0)
    return sign * shaped


class MotionController(QObject):
    """Receives normalized inputs and issues Sangaboard commands."""

    motion_blocked          = Signal(str)   # "endstop", "soft_limit_stage", etc.
    joystick_cal_done       = Signal()
    joystick_center_changed = Signal()
    deadzone_changed        = Signal()
    soft_limits_changed     = Signal()
    position_reset          = Signal(int, int, int)
    stage_zeroed            = Signal()
    backlash_slack_changed  = Signal(float, float, float)
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

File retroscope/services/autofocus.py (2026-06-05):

"""Contrast-based autofocus service. 

Performs a configurable coarse/fine Z sweep, samples focus scores from CameraService after each settled move, then commits to the best fine position when valid.

Note: Partially AI-generated (Parabolic peak interpolation)
"""

from __future__ import annotations

import logging
import threading
import time
from statistics import median
from typing import Any

from PySide6.QtCore import QObject, QThread, Signal, Slot

from retroscope.domain.focus_metrics import parabolic_peak

logger = logging.getLogger(__name__)

_DEFAULT_RANGE_MULTIPLIER = 10

# Hard limits, clamp config values 
_MIN_COARSE_POSITIONS = 7
_MAX_COARSE_POSITIONS = 41
_MIN_FINE_POSITIONS = 5
_MAX_FINE_POSITIONS = 41
_MIN_SETTLE_MS = 50
_MAX_SETTLE_MS = 2000
_MIN_MOVE_START_MS = 100
_MAX_MOVE_START_MS = 3000
_MIN_SAMPLES_PER_POSITION = 1
_MAX_SAMPLES_PER_POSITION = 5
_MIN_CONFIDENCE_FLOOR = 0.0
_MIN_CONFIDENCE_CEIL = 5000.0


def _profile_autofocus_range(profile) -> int:
    configured = int(getattr(profile, "autofocus_range_steps", 0) or 0)
    if configured > 0:
        return configured
    dof = int(getattr(profile, "dof_steps", 1) or 1)
    stack = int(getattr(profile, "focus_stack_step", 1) or 1)
    return max(200, dof * _DEFAULT_RANGE_MULTIPLIER, stack * 40)


def _odd_count(value: Any, lo: int, hi: int, default: int) -> int:
    count = _clamp_int(value, lo, hi, default)
    if count % 2 == 0:
        count = min(hi, count + 1)
    return count


def centered_sweep_offsets(step: int, count: int) -> list[int]:
    """Return sampled offsets: centre, upward half, then downward half."""
    count = max(1, int(count))
    if count % 2 == 0:
        count += 1
    half = count // 2
    return [0] + [step * i for i in range(1, half + 1)] + [-step * i for i in range(1, half + 1)]


def autofocus_sample_positions(profile, coarse_positions: int = 21) -> list[int]:
    """Return sampled coarse offsets: centre, upward half, then downward half."""
    coarse_positions = _odd_count(coarse_positions, _MIN_COARSE_POSITIONS, _MAX_COARSE_POSITIONS, 21)
    search_range = _profile_autofocus_range(profile)
    half = coarse_positions // 2
    step = max(5, int(round(search_range / max(1, half))))
    return centered_sweep_offsets(step, coarse_positions)


def _clamp_int(value: Any, lo: int, hi: int, default: int) -> int:
    try:
        v = int(value)
    except (TypeError, ValueError):
        return default
    return max(lo, min(hi, v))


def _clamp_float(value: Any, lo: float, hi: float, default: float) -> float:
    try:
        v = float(value)
    except (TypeError, ValueError):
        return default
    return max(lo, min(hi, v))


class _AutofocusWorker(QThread):
    """Background thread that executes the coarse + fine Z sweep."""

    progress = Signal(float)      # 0.0–1.0
    failed   = Signal(str)        
    finished = Signal()

    def __init__(self, camera_svc, motion_ctrl, objective_mgr, config, parent=None):
        super().__init__(parent)
        self._camera = camera_svc
        self._motion = motion_ctrl
        self._obj    = objective_mgr
        self._config = config
        self._cancel = False
        self._cancel_event = threading.Event()
        # Defaults (overwritten from config)
        self._settle_s            = 0.30
        self._move_start_s        = 0.80
        self._coarse_positions    = 21
        self._fine_positions      = 21
        self._samples_per_position = 2
        self._min_confidence      = 50.0
        self._analysis_fps        = 8

    def request_cancel(self) -> None:
        self._cancel = True
        self._cancel_event.set()

    def _sleep_cancelable(self, delay_s: float) -> bool:
        if delay_s <= 0.0:
            return not self._cancel
        return not self._cancel_event.wait(delay_s)

    # Config (read at the start of every run)
    def _load_config(self) -> None:
        cfg = self._config
        get = cfg.get if cfg is not None else (lambda *_a, **_k: None)
        self._settle_s = _clamp_int(
            get("autofocus.settle_ms", 300), _MIN_SETTLE_MS, _MAX_SETTLE_MS, 300
        ) / 1000.0
        self._move_start_s = _clamp_int(
            get("autofocus.move_start_ms", 800), _MIN_MOVE_START_MS, _MAX_MOVE_START_MS, 800
        ) / 1000.0
        self._coarse_positions = _odd_count(
            get("autofocus.coarse_positions", 21),
            _MIN_COARSE_POSITIONS, _MAX_COARSE_POSITIONS, 21,
        )
        self._fine_positions = _odd_count(
            get("autofocus.fine_positions", 21), _MIN_FINE_POSITIONS, _MAX_FINE_POSITIONS, 21
        )
        self._samples_per_position = _clamp_int(
            get("autofocus.samples_per_position", 2),
            _MIN_SAMPLES_PER_POSITION, _MAX_SAMPLES_PER_POSITION, 2,
        )
        self._min_confidence = _clamp_float(
            get("autofocus.min_confidence", 50.0),
            _MIN_CONFIDENCE_FLOOR, _MIN_CONFIDENCE_CEIL, 50.0,
        )
        self._analysis_fps = _clamp_int(get("camera.fps", 8), 1, 30, 8)

    # Per-position score
    def _focus_score_timeout_s(self) -> float:
        frame_period_s = 1.0 / max(1, self._analysis_fps)
        return min(2.5, max(0.35, self._settle_s + 0.3, frame_period_s * 2.5))

    def _raw_focus_sequence(self) -> int:
        if hasattr(self._camera, "raw_focus_sequence"):
            return int(self._camera.raw_focus_sequence())
        return 0

    def _grab_score(self) -> float | None:
        """Median of live focus scores. The sequence is captured after the motor settle delay."""

        if not hasattr(self._camera, "wait_for_next_raw_focus_score"):
            logger.info("[autofocus] camera service has no raw focus-score stream")
            return None
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

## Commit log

2026-06-05 New keyboard shortcut for encoder step
    [input_manager.py]
2026-06-05 Implemented debug toggles for frame analysis and live preview
2026-06-05 Reworked frame analysis to run on separte thread
    [camera_service.py]
2026-06-05 Adjusted joystick sample timeout
2026-06-05 Improve autofocus frame freshness
2026-06-05 Trying to fix the autofocus freshness issue
    [autofocus.py]
2026-06-05 Copying frame for processing to free up main thread
2026-06-05 Switching from dynamic joystick smoothing to fixed command dispatch
    [motion_controller.py]
2026-06-05 Implemented camera reconnect logic
2026-06-05 Added guard for button events during new video device change
2026-06-05 Reworked the camera reconnect logic
2026-06-05 Added noise supression on gpio buttons
    [button_manager.py, buttons.py]
2026-06-05 Added an no camera placeholder in live view
2026-06-05 Added backlash visu in live view sidebar
    [motion_controller.py]
2026-06-06 Adjused height and flipped y axis
2026-06-06 Fixed video recording after camera pipeline rework
    [camera_service.py]
2026-06-06 "Reset defaults" not resets the whole config not just the active objective
    [button_manager.py, config_store.py, motion_controller.py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]
2026-06-06 Added joystick backlash compensation
    [motion_controller.py]
2026-06-06 Reworked gallery with thumbnails, caches and lazy loading
    [image_store.py]
2026-06-06 Reworked tap-to-move by calc frame pixels to steps
    [motion_controller.py]
2026-06-06 Use frame tap size in tap-to-move calc
2026-06-07 Fixed remaining warnings/errors in the log during runtime
    [image_store.py]
2026-06-08 Added pcb files and fusion model
    [Retroscope-B_Cu.gbr, Retroscope-B_Mask.gbr, Retroscope-B_Paste.gbr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]
2026-06-08 Protect joystick backlash compensation moves from coalescing
    [input_manager.py, motion_controller.py, sangaboard.py]
2026-06-09 Trying to fix remaining log warnings
    [sangaboard.py]
2026-06-09 Fixing calibration eval
2026-06-09 Increased settle time and add fresh frame grab for eval
2026-06-09 Updated sangaboard driver to separate blocking and query moves with protected flag
2026-06-11 Added evaluation results
    [calibration_repeat_20260610_214331.csv, motion_accuracy_20260610_181903.csv, stage_scale_20260610_180412.csv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]
2026-06-16 Removed drill file reference
